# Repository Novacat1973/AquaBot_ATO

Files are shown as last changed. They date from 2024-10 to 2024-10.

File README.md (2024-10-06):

# AquaBot_ATO - Automatic Top-Off System

## Project Description

AquaBot_ATO is an innovative automatic top-off system designed specifically for aquariums. It efficiently regulates water levels while ensuring the safety of aquarium operations. By utilizing modern technology and intelligent safety mechanisms, AquaBot_ATO guarantees that your aquarium is always optimally supplied with water, eliminating the risk of overflow.

## System Overview

The core of the AquaBot_ATO system is an Arduino Nano, which controls and monitors all functions. The system is powered by a 12V power supply, with a step-down converter reducing the voltage to 5V for the Arduino. 

### Water Level Sensors

Stainless steel probes are used as water level sensors, divided into two separate systems:

1. **Main Control:** The first sensor is directly connected to the Arduino and measures the water level hourly. A 10k resistor ensures that the Arduino reads the sensor value through an analog input. The sensor checks for a stable high or low value over a period of 5 seconds to determine if it is in contact with water.

2. **Emergency Shutdown:** The second sensor is decoupled from the Arduino and serves as a safety mechanism. If the water level reaches above a critical point, a MOSFET (IRLZ44N) shuts down the pump to prevent overflow. 

## Safety Mechanisms

AquaBot_ATO implements two essential safety mechanisms to prevent aquarium overflow:

- **Pump Control:** The Arduino allows the pump to run for a maximum of 10% longer than the previous pumping duration. If this time is exceeded, the Arduino deactivates the MOSFET and triggers an alarm that requires confirmation before a new refill operation can start.

- **Emergency Shutdown:** If the water level exceeds the sensor and activates the emergency shutdown, a second MOSFET is deactivated, cutting off the power supply to the pump to prevent overflow.

## User Interaction and Status Display

The system status is indicated by an RGB LED on the sensor and displayed on a connected OLED display. A simple push button allows users to manually interact with the device and check the system status.

- **Constant Green:** Water is filled up to the desired level.
- **Blinking Blue:** Pump is running / water is filling up.
- **Blinking Red:** Error detected in the system.
- **Constant Yellow:** Refill reservoir is about to be empty (warning).
- **Blinking Yellow:** Refill reservoir is critically low (immediate attention required).

### OLED Display

The system features an OLED display with a main view and a small menu. 

The main view gives information about the current systems status, how much water evaporates, how many water the reservoir still remains and for how many days the remaining water lasts until it needs to be refilled. 

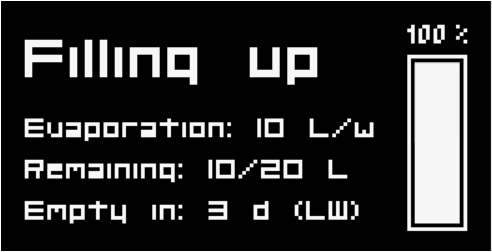
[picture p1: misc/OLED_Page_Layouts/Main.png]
Main


To enter the menu, do a Long Press (2+ sec.). There are two menu points you can choose from. Either telling the system that you have refilled your reservoir or setting the net volume of your reservoir (the amount of water which can actually be pumped out). You can choose the menu point by doing a Short Press. A Double Press selects the point.

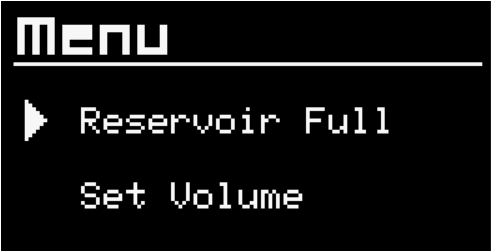
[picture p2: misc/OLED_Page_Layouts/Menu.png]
Menu


Long Press the point "Reservoir Full", restores the remaining volume of the reservoir to the set volume. After a short selection screen the menu exits automatically.

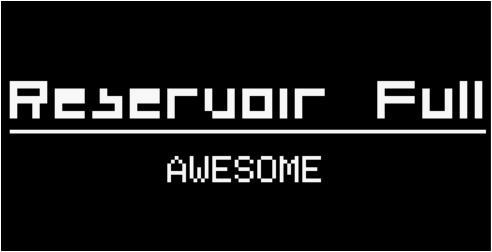
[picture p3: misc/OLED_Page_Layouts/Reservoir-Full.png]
Reservoir-Full


Long Press the point "Set Volume" leads to a settings page where you can select the net volume of the water which can actually be pumped into the aquarium, taking into account that the reservoir can't be filled 100% to the top and that always a small amount of water will remain at the bottom which can't be sucked up by the pump. This net volume needs to be tested individually. The max. net volume available is 50 liters.

You can change 1 by a Short Press and 10 by Double Press. When you have reached your desired net volume, define it via a Long Press and the menu will automatically exit after a short selection screen. 

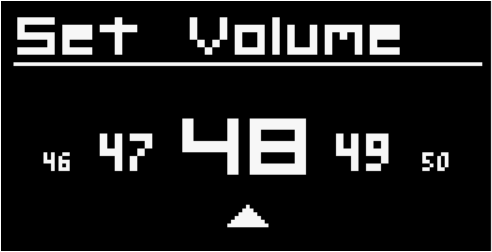
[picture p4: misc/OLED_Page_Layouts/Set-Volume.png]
Set-Volume

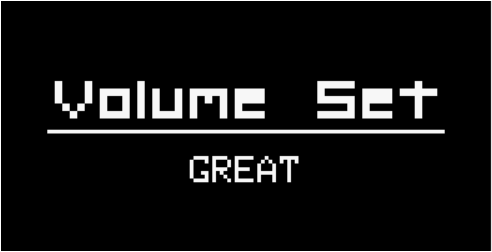
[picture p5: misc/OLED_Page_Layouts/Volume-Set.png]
Volume-Set


## Protection Measures

To protect the electronics from voltage spikes and inductive backflows, a capacitor (100-400 µF electrolytic capacitor) and a diode (1N5401) are integrated. These components ensure the longevity and reliability of the system, especially during the pump's on/off cycles.

## Conclusion

AquaBot_ATO is a well-thought-out and safe solution for automatic water level control in aquariums. With its advanced safety mechanisms and user-friendly interface, it provides aquarium owners with the assurance that their fish and plants are always in an optimal environment.

## Components Used

- **Microcontroller:** Arduino Nano
- **Power Supply:** 12V power supply with a step-down converter (12V to 5V)
- **Water Level Sensors:** Stainless steel probes
- **MOSFETs:** IRLZ44N
- **Diode:** 1N5401
- **Capacitor:** 100-400 µF electrolytic capacitor
- **Resistor:** 10k resistor

Feel free to contribute to the project or reach out with any questions or suggestions!

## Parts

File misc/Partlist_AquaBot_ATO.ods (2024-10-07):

Part | Prize | Source
Arduino Nano | 0.00 EUR | available
12 VDC 2A power supply | 0.00 EUR | available
2x MOSFET IRLZ44N | 0.00 EUR | available
5.5 mm barrel jack | 3.56 EUR | https://www.androegg.de/shop/2-stk-pcs-hohlstecker-anschluss-barrel-jack-socket-55-x-25-mm-metall/
1x 6-pin Plug & Connector | 3.04 EUR | https://www.androegg.de/shop/gx16-2-3-4-5-6-7-8-9-10-pin-o16mm-stecker-buchse-steckverbinder/
1x 2-pin Plug & Connector | 2.95 EUR | https://www.androegg.de/shop/gx16-2-3-4-5-6-7-8-9-10-pin-o16mm-stecker-buchse-steckverbinder/
Micro Push Button | 0.00 EUR | available
WS2812B LED (single) | 0.00 EUR | available
1.54 128x64 OLED Display | 8.27 EUR | https://www.androegg.de/shop/154-ssd1309-i2c-driver-oled-lcd-display-128x64-weiss-blau/
12→5VDC Step Down Buck | 2.95 EUR | https://www.androegg.de/shop/mp1584en-spannungsregler-3a-7-26vin-5v-fix-vout-step-down-buck-converter/
Diode 1N5401
Fuse
Fuse holder
Electrolytic Capacitor 100-400 micF
Water hose
Dosing pump | 4.00 EUR | eBay
2 wire cable
6 wire cable
TOTAL | 24.77 EUR

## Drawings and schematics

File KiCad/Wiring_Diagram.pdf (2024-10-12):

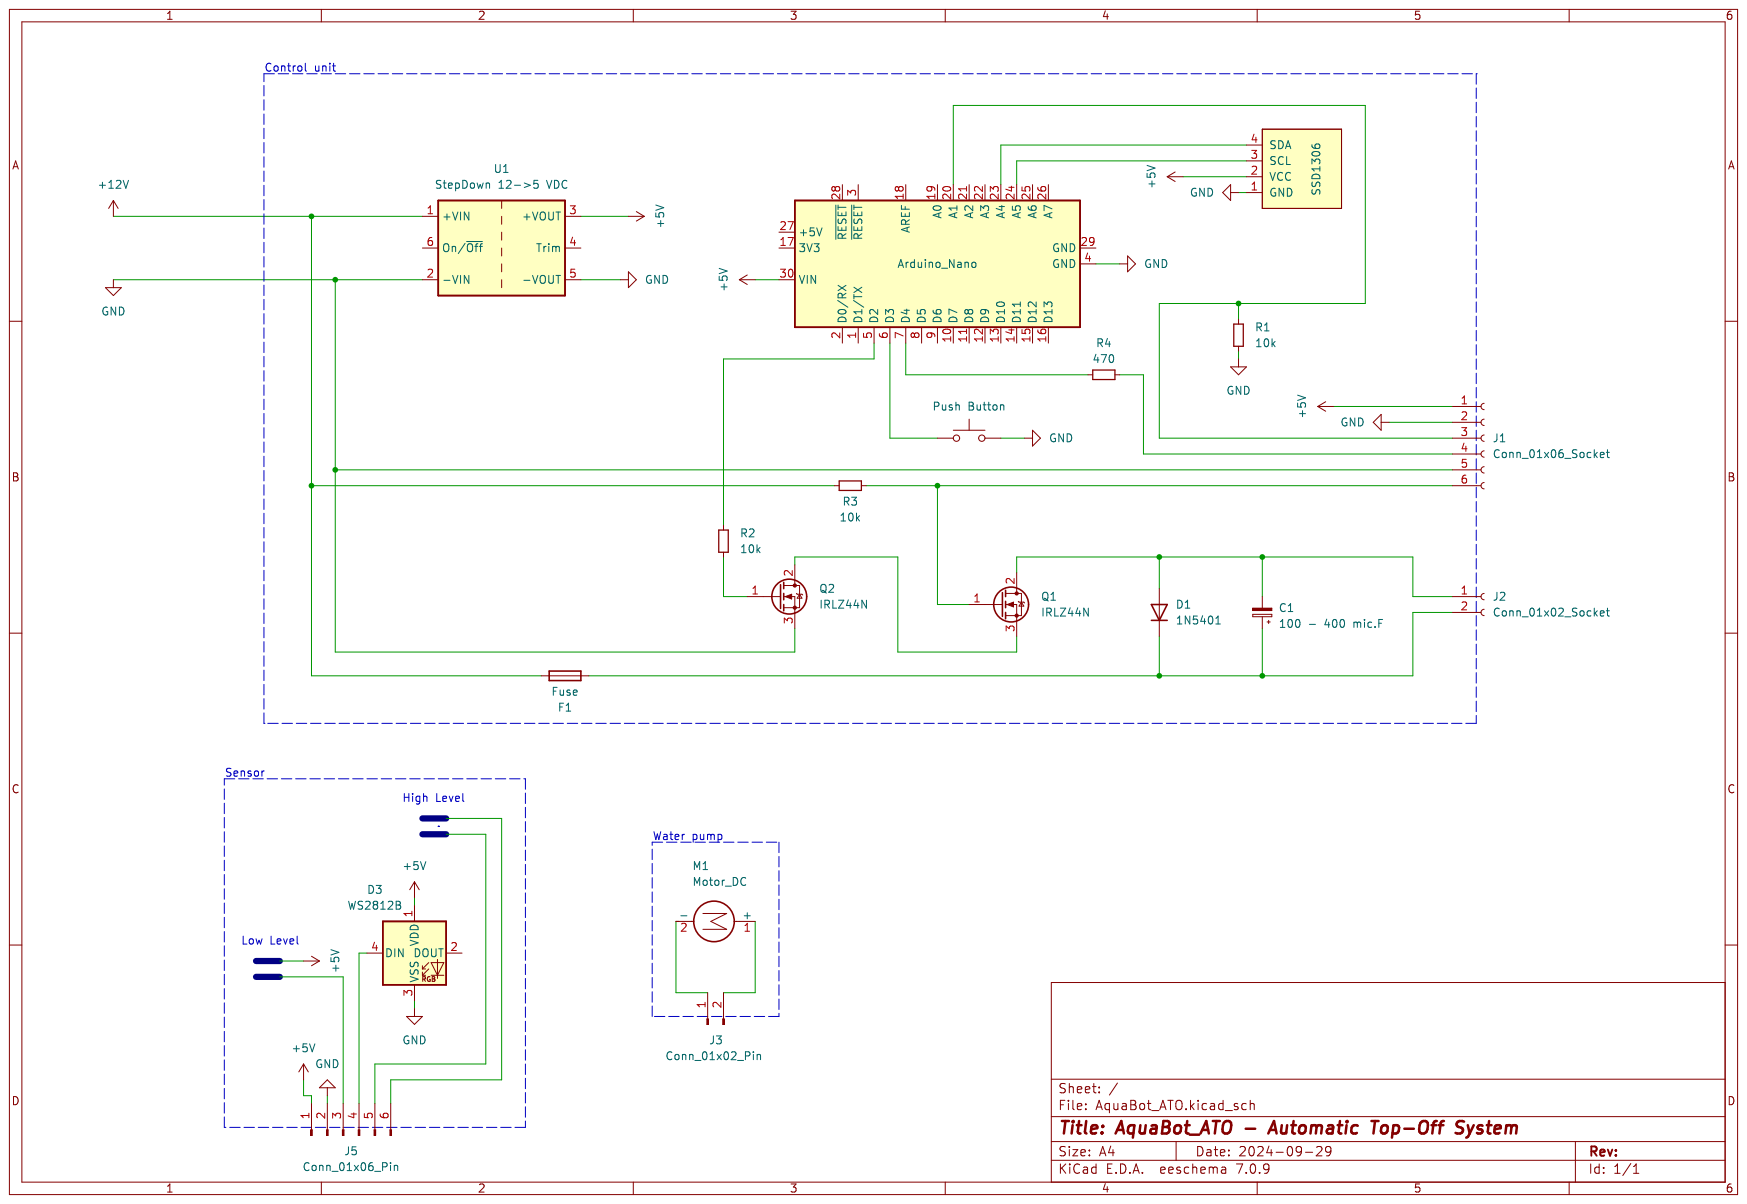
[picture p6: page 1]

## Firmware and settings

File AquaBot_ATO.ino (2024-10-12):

// Implement error handlings
// Reduce Code Duplication
// Add function documentation to each function header: explaining its purpose, parameters and return values
// Integration of the RGB sensor LED via LightWS2812 library

// Include libraries for the OLED display management
#include <SPI.h>
#include <Wire.h>
#include <Adafruit_GFX.h>
#include <Adafruit_SSD1306.h>

// Include fonts for the OLED display
#include <Fonts/Org_01.h>
#include <Fonts/TomThumb.h>

#define SCREEN_WIDTH 128 // OLED display width, in pixels
#define SCREEN_HEIGHT 64 // OLED display height, in pixels

// Declaration for an SSD1306 display connected to I2C (SDA, SCL pins)
#define OLED_RESET     -1 // Reset pin # (or -1 if sharing Arduino reset pin)
#define SCREEN_ADDRESS 0x3D ///< See datasheet for Address; 0x3D for 128x64, 0x3C for 128x32
Adafruit_SSD1306 display(SCREEN_WIDTH, SCREEN_HEIGHT, &Wire, OLED_RESET);

// Debug Mode
// When debugging is disabled, the code that generates debug output is not included in the compiled program.
#define DEBUG_MODE  // Uncomment this line to enable debug mode

#ifdef DEBUG_MODE
#define DEBUG_PRINT(x) Serial.print(x)
#define DEBUG_PRINTLN(x) Serial.println(x)
#else
#define DEBUG_PRINT(x)
#define DEBUG_PRINTLN(x)
#endif

// Pin assignments
const int sensorPinInput = A1;  // A1 for water sensor input
const int mosfetPin = 2;        // D2 for MOSFET control
const int buttonPin = 3;        // D3 for button input

// Time intervals and thresholds (in milliseconds)
const unsigned long readingInterval = 10000;  // Time interval for checking water level
const int stableReadingThreshold = 350;       // Analog reading threshold indicating water contact
const unsigned long stableDuration = 2000;    // Duration for stable sensor reading to confirm water level
const float maxPumpDurationFactor = 1.1;      // Safety factor: max pump duration increase for overflow prevention

// Button timing thresholds
const unsigned long debounceDelay = 50;           // Debounce delay in milliseconds
const unsigned long shortPressDuration = 350;     // Maximum duration for a short press (in ms)
const unsigned long doublePressInterval = 400;    // Maximum interval between two short presses (in ms)
const unsigned long longPressDuration = 1000;     // Minimum duration for a long press (in ms)
const unsigned long pressAndHoldDuration = 2000;  // Minimum duration for press and hold (2 seconds)

// Variables for tracking time and readings
unsigned long previousCheckMillis = 0;   // Last time water level was checked
unsigned long pumpStartMillis = 0;       // Time when the pump was activated
unsigned long previousFillDuration = 0;  // Duration of the last filling
unsigned long lastButtonPressTime = 0;   // Time of the last button press
unsigned long buttonPressStartTime = 0;  // Time when the button was first pressed
unsigned long lastShortPressTime = 0;    // Time of the last short press

// Flags
bool initialRun = true;    // Flag to indicate first run since power-up
bool alarmRaised = false;  // Flag to indicate if the alarm has been raised due to long pump runtime

// Enumeration to define pump states
enum class PumpState {
  OFF,      // Pump is off
  RUNNING,  // Pump is running (regular water level monitoring)
  PRIMING   // Pump is priming (manual activation via press-and-hold)
};
PumpState pumpState = PumpState::OFF;  // Initial state of the pump

// Enumeration to define button states
enum class ButtonState {
  IDLE,
  DEBOUNCING,
  PRESSED,
  WAIT_DOUBLE_PRESS,
  HOLDING
};
ButtonState buttonStateMachine = ButtonState::IDLE;

// Button state variables
bool buttonState = HIGH;      // Current button state
bool lastButtonState = HIGH;  // Previous button state
enum class ButtonPressType {  // Enum to define button press types
  NONE,
  SHORT_PRESS,
  DOUBLE_SHORT_PRESS,
  LONG_PRESS,
  PRESS_AND_HOLD
};
ButtonPressType buttonPressType = ButtonPressType::NONE;

// Enumeration to define OLED display states
enum class DisplayState {
  MAIN_VIEW,            // Showing the main system information
  MENU_SELECTION,       // Menu where user selects "Reservoir Full" or "Set Volume"
  MENU_RESERVOIR_FULL,  // Option to reset reservoir
  MENU_SET_VOLUME,      // Option to set net reservoir volume
  SETTING_VOLUME        // Adjusting the net volume of the reservoir
};
DisplayState displayState = DisplayState::MAIN_VIEW;  // Initial display state

// Function prototypes
void checkWaterLevel();
void activatePump();
void deactivatePump();
void monitorPumpDuringFilling();
void checkButtonPress();
void handleButtonPress();
void processButtonPress(ButtonPressType pressType);
bool isWaterLevelStable(int initialReading);

void setup() {

// Initialize serial communication (for debugging)
  Serial.begin(9600);

	// SSD1306_SWITCHCAPVCC = generate display voltage from 3.3V internally
  delay(100);  // Add this before display.begin()
  if(!display.begin(SSD1306_SWITCHCAPVCC, SCREEN_ADDRESS)) {
    Serial.println(F("SSD1306 allocation failed"));
    for(;;); // Don't proceed, loop forever
  }

  // Show initial display buffer contents on the screen --
  // the library initializes this with an Adafruit splash screen.
  display.display();
  delay(2000); // Pause for 2 seconds

  // Clear the buffer
  display.clearDisplay();

  // Set pin modes
  pinMode(sensorPinInput, INPUT);
  pinMode(mosfetPin, OUTPUT);
  pinMode(buttonPin, INPUT_PULLUP);  // Button with internal pull-up resistor

  
  // Initialize states
  digitalWrite(mosfetPin, LOW);  // Set MOSFET initially off




  // Initialize the OLED display
  //setupOLED();
}

void loop() {

  //displayMainView();

  // Override all actions if the pump is in PRIMING state
  if (pumpState != PumpState::PRIMING) {
    if (!alarmRaised && pumpState == PumpState::OFF) {
      // If the pump is off, check water level at regular intervals
      checkWaterLevel();
    } else if (pumpState == PumpState::RUNNING) {
      // If the pump is running, monitor its duration to avoid overflow
      monitorPumpDuringFilling();
    }
  }

  // Continuously check for button presses
  checkButtonPress();

  // Process button press types based on detected press type
  handleButtonPress();
}


/* ---------------------------------------------------------------
 ------------- Main MONITORING and CONTROL functions -------------
 ----------------------------------------------------------------*/

// Helper function to check if water level is stable over a specified duration
// Parameters:
// - initialReading: The initial analog reading of the water sensor
// Returns: true if the water level remains stable for the stableDuration, false otherwise
bool isWaterLevelStable(int initialReading) {
  unsigned long stableStart = millis();
  // Continuously check sensor values over stableDuration
  while (millis() - stableStart <= stableDuration) {
    int sensorValue = analogRead(sensorPinInput);  // Read sensor value

    // Determine if the state has changed from initial reading (indicates instability)
    if ((sensorValue >= stableReadingThreshold && initialReading < stableReadingThreshold) || (sensorValue < stableReadingThreshold && initialReading >= stableReadingThreshold)) {
      return false;  // State changed, not stable
    }
  }
  return true;  // State remained stable throughout the duration
}

// Function to check the water level at set intervals
// Reads the water sensor value and activates the pump if water level is low
void checkWaterLevel() {
  unsigned long currentMillis = millis();

  // Check if the reading interval has passed
  if (currentMillis - previousCheckMillis >= readingInterval) {
    previousCheckMillis = currentMillis;

    // Read initial sensor value
    int sensorValue = analogRead(sensorPinInput);

    // Check if water level is stable before making decisions
    if (isWaterLevelStable(sensorValue)) {
      if (sensorValue >= stableReadingThreshold) {
        DEBUG_PRINTLN("Water level is stable and high.");
        // Water is detected, no action needed
      } else {
        DEBUG_PRINTLN("Water level is low, activating pump.");
        activatePump();  // Water is low, activate the pump
      }
    } else {
      DEBUG_PRINTLN("Unstable readings detected, ignoring this cycle.");
    }
  }
}

// Function to activate the pump
void activatePump() {
  digitalWrite(mosfetPin, HIGH);  // Activate MOSFET to start pump
  pumpStartMillis = millis();     // Record the pump start time

  // Set pump state based on the current scenario
  if (pumpState == PumpState::PRIMING) {
    DEBUG_PRINTLN("Pump priming mode activated.");
  } else {
    DEBUG_PRINTLN("Pump activated.");
    pumpState = PumpState::RUNNING;  // Set pump state to running
  }
}


// Function to deactivate the pump
void deactivatePump() {
  digitalWrite(mosfetPin, LOW);                             // Deactivate MOSFET to stop pump
  unsigned long fillDuration = millis() - pumpStartMillis;  // Calculate runtime duration

  DEBUG_PRINT("Pump deactivated. Runtime: ");
  DEBUG_PRINT(fillDuration / 1000.0);
  DEBUG_PRINTLN(" s");

  // Reset pump state to OFF
  pumpState = PumpState::OFF;
}

// Function to monitor the pump's behavior during filling
// Checks if the pump has been running for too long or if water level is stable to deactivate
void monitorPumpDuringFilling() {
  unsigned long currentMillis = millis();
  unsigned long maxPumpDuration = previousFillDuration * maxPumpDurationFactor;  // Calculate the max allowed pump duration

  // Check if the pump has been running for too long (overflow prevention)
  if (!initialRun && currentMillis - pumpStartMillis >= maxPumpDuration) {
    DEBUG_PRINTLN("Pump running too long, deactivating pump for safety.");
    deactivatePump();
    alarmRaised = true;  // Raise an alarm that must be acknowledged before any other action is taken
    DEBUG_PRINTLN("ALARM raised. Waiting for acknowledgement.");
    return;  // Exit function if pump duration exceeded to prevent overflow
  }

  // Read initial sensor value
  int initialSensorValue = analogRead(sensorPinInput);

  // If the initial sensor value is below the threshold (no water detected), skip stability check but continue monitoring
  if (initialSensorValue < stableReadingThreshold) {
    DEBUG_PRINTLN("Water not detected initially. Continuing to monitor pump duration.");
    return;  // Exit early as no water is detected
  }

  // If the initial value is high (indicating water is detected), start stability check
  if (isWaterLevelStable(initialSensorValue)) {
    DEBUG_PRINTLN("Water detected, deactivating pump.");
    deactivatePump();
    initialRun = false;
    previousFillDuration = currentMillis - pumpStartMillis;  // Record fill duration
  }
}


/* ---------------------------------------------------------------
 --------------------- BUTTON HANDLING ---------------------------
 ----------------------------------------------------------------*/

// Function to handle button presses
// Check and process button state transitions, debouncing, and press types
void checkButtonPress() {
  bool currentButtonState = digitalRead(buttonPin);  // Read the current state of the button (active-low)

  switch (buttonStateMachine) {
    case ButtonState::IDLE:
      if (currentButtonState == LOW) {  // Button pressed
        buttonStateMachine = ButtonState::DEBOUNCING;
        buttonPressStartTime = millis();  // Record when the button was pressed
      }
      break;

    case ButtonState::DEBOUNCING:
      if (millis() - buttonPressStartTime > debounceDelay) {  // Debounce delay passed
        if (currentButtonState == LOW) {                      // Button is still pressed
          buttonStateMachine = ButtonState::PRESSED;
          DEBUG_PRINTLN("Button pressed, start timing.");  // Print button pressed message
        } else {
          buttonStateMachine = ButtonState::IDLE;  // False trigger, go back to IDLE
        }
      }
      break;

    case ButtonState::PRESSED:
      if (currentButtonState == HIGH) {  // Button released
        unsigned long pressDuration = millis() - buttonPressStartTime;
        if (pressDuration < shortPressDuration) {  // Short press detected
          if (millis() - lastShortPressTime <= doublePressInterval) {
            buttonPressType = ButtonPressType::DOUBLE_SHORT_PRESS;  // Double short press detected
            buttonStateMachine = ButtonState::IDLE;                 // Reset state after confirming double press
          } else {
            lastShortPressTime = millis();                        // Record time of the first short press
            buttonPressType = ButtonPressType::NONE;              // Do not process action yet, wait for second press
            buttonStateMachine = ButtonState::WAIT_DOUBLE_PRESS;  // Wait for a possible second press
          }
        } else if (pressDuration >= longPressDuration && pressDuration < pressAndHoldDuration) {  // Long press detected
          buttonPressType = ButtonPressType::LONG_PRESS;
          buttonStateMachine = ButtonState::IDLE;
        } else if (pressDuration >= pressAndHoldDuration) {  // Transition to press and hold
          buttonPressType = ButtonPressType::PRESS_AND_HOLD;
          buttonStateMachine = ButtonState::HOLDING;  // Transition to HOLDING state
        }
      } else if (millis() - buttonPressStartTime >= pressAndHoldDuration) {  // Button held for pressAndHoldDuration
        buttonPressType = ButtonPressType::PRESS_AND_HOLD;
        buttonStateMachine = ButtonState::HOLDING;  // Transition to HOLDING state
      }
      break;

    case ButtonState::HOLDING:
      if (currentButtonState == HIGH) {           // Button released
        buttonStateMachine = ButtonState::IDLE;   // Reset to IDLE on release
        buttonPressType = ButtonPressType::NONE;  // Clear press type
        deactivatePump();                         // Turn off pump when button is released
      } else {
        buttonPressType = ButtonPressType::PRESS_AND_HOLD;            // Keep PRESS_AND_HOLD active
        if (pumpState != PumpState::PRIMING) {                        // Enter priming mode only once
          DEBUG_PRINTLN("Press and Hold action: Priming the pump.");  // Print message once
          activatePump();                                             // Turn on the pump while holding
          pumpState = PumpState::PRIMING;                             // Set pump state to priming
        } else {
          // Pump is already running, print running status
          DEBUG_PRINTLN("Pump is running.");
        }
      }
      break;

    case ButtonState::WAIT_DOUBLE_PRESS:
      if (millis() - lastShortPressTime > doublePressInterval) {
        buttonPressType = ButtonPressType::SHORT_PRESS;  // No second press within interval, confirm short press
        buttonStateMachine = ButtonState::IDLE;          // Return to IDLE state and process short press action
      }
      if (currentButtonState == LOW) {                 // Second press detected
        buttonStateMachine = ButtonState::DEBOUNCING;  // Go to debounce state for second press
        buttonPressStartTime = millis();               // Start timing the second press
      }
      break;
  }

  // Update the lastButtonState to the current state
  lastButtonState = currentButtonState;
}

// Function to handle detected button presses and execute actions based on press type
void handleButtonPress() {
  switch (buttonPressType) {
    case ButtonPressType::SHORT_PRESS:
      DEBUG_PRINTLN("Short press action.");
      // Execute short press action here
      break;

    case ButtonPressType::DOUBLE_SHORT_PRESS:
      DEBUG_PRINTLN("Double short press action.");
      // Execute double short press action here
      break;

    case ButtonPressType::LONG_PRESS:
      DEBUG_PRINTLN("Long press action.");
      if (alarmRaised) {
        DEBUG_PRINTLN("Alarm acknowledged and reset.");
        alarmRaised = false;  // Reset the alarm when long press is detected
      }
      // Execute other long press action here
      break;

    case ButtonPressType::PRESS_AND_HOLD:
      // Pump activation logic is handled directly in the HOLDING state of the state machine.
      // No additional logic needed here.
      break;

    case ButtonPressType::NONE:
      // No press action
      break;
  }

  // Reset press type after handling
  buttonPressType = ButtonPressType::NONE;
}


/* ---------------------------------------------------------------
 ------------------- OLED DISPLAY interaction --------------------
 ----------------------------------------------------------------*/

// Function to initialize the OLED display
void setupOLED() {
  if (!display.begin(SSD1306_SWITCHCAPVCC, 0x3D)) {  // Address 0x3D (61) for 128x64
    DEBUG_PRINTLN(F("SSD1306 allocation failed"));
	//for(;;); // Don't proceed, loop forever
  }

  display.display();
  delay(2000);  // Pause for 2 seconds
  display.clearDisplay();
}


// Function to display the main system information
void displayMainView() {
  display.clearDisplay();

  display.setFont(&Org_01);
  display.setTextSize(2);

  // Show system states
  display.setCursor(5, 17);

  // Check if an alarm has been raised
  if (alarmRaised) {
    display.println("!! ERROR !!");
  } else {
    // Show pump state if no alarm is raised
    switch (pumpState) {
      case PumpState::RUNNING:
        display.println("Filling up");
        break;
      case PumpState::PRIMING:
        display.println("Priming");
        break;
      case PumpState::OFF:
        display.println("In level");
        break;
    }
  }

  display.setTextSize(1);

  // Show the evaporation rate in liter / week
  display.setCursor(5, 34);
  display.println("Evaporation: 10 L/w");

  // Show how many water remains in the reservoir
  display.setCursor(5, 45);
  display.println("Remaining: 10/20 L");

  // Show how many days the reservoir still lasts until a refill is required
  // LW (Low Warning)
  // LA (Low Alarm -> no pump start possible)
  display.setCursor(5, 56);
  display.println("Empty in: 3 d (LW)");

  // Show bar graph of the reservoir filling level and percentage of filling
  display.setFont(&TomThumb);
  display.setCursor(107, 10);
  display.println("100 %");
  display.drawRect(107, 13, 16, 47, 1);
  display.fillRect(109, 35, 12, 23, 1);

  // Update the OLED display
  display.display();
}

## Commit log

2024-09-29 update the readme and added misc folder
    [Partlist_AquaBot_ATO.ods]
2024-09-29 added kicad folder
    [AquaBot_ATO.kicad_pcb, AquaBot_ATO.kicad_sch]
2024-09-30 initial commit of the arduino code
    [AquaBot_ATO.kicad_sch]
2024-10-01 Improved the schematics and added a comment to the code
    [AquaBot_ATO.kicad_sch]
2024-10-03 Added button handling and priming mode
2024-10-04 Adding a debug mode to omit Serial.print commands
2024-10-04 Did some code refactorings and adding an alarm handling for a too long running pump.
    [AquaBot_ATO.ino]
2024-10-06 Added OLED display layouts to the misc folder. Updated the readme
    [Reservoir-Full_layout.json]
2024-10-07 Updated the part list
    [Partlist_AquaBot_ATO.ods]
2024-10-12 Integrating a Arduino Simulation
    [AquaBot_ATO.kicad_sch]
